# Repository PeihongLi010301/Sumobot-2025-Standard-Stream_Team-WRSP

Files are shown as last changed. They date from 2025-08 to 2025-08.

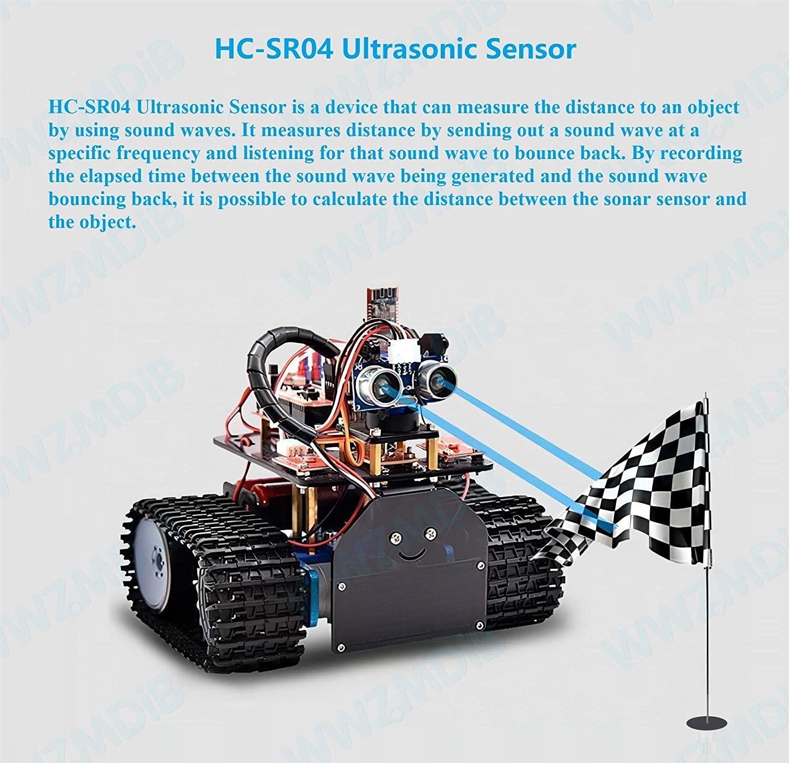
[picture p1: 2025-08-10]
Sumobot组件技术文档/HC-SR04 Specs4.jpg

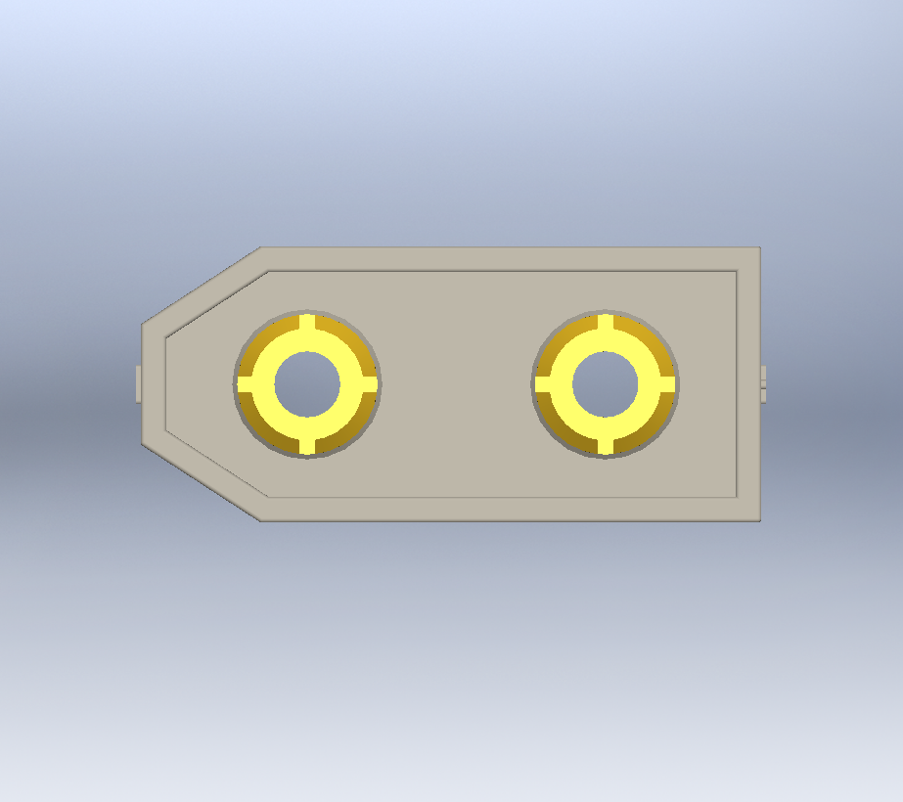
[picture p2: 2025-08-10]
MechanicalDesign_HM/Kit Components/LiPO/xt60-male-connector-3.snapshot.5/male connector top.png

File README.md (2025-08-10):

# Sumobot 2025 Standard Stream 相扑机器人标准组比赛
- 比赛组织方：UNSW Robotics and Mechatronics Society (RAMSoc)
- 团队名：WRSP（后改名为LRSP但未正式提交赛组委修改）
- 团队成员：李培泓（Peihong Li），余政阳（Zhengyang Yu），Suria，Sharath
- 比赛时间：2025年7月31日
- 核心硬件：Arduino Nano + L298N电机驱动模块 + HC-SR04超声波传感器模块×3 + KY-033红外传感器模块×2 + 直流减速电机×2

## 比赛概述
Sumobot 比赛遵循传统相扑比赛的核心规则，有两台自主机器人在擂台上对抗，目标是将对手推出擂台外
### 赛制规则
- 比赛流程：
  - 每场比赛最多 3 局，每局最长 2 分钟
  - 裁判发出开始信号后需等待 5 秒才可行动
  - 当对手被推出擂台外（身体任何部分触地）即判胜
  - 若时间到未分出胜负，裁判将根据技术表现等决定胜负
- 限制：
  - 最大尺寸：200mm × 200mm
  - 最大重量：1kg
  - 预算不超过 A$200
  - 只能使用组委会提供的套件和预先批准的额外零件
  - 不可改动传动系统，不可使用磁铁或粘性物质增加抓地力
### 擂台规格
- 外径：120cm
- 内径（黑色比赛区）：115cm
- 白边宽度：2.5cm
- 材质：18mm厚MDF板，表面喷漆

## 我们的机器人设计
### 机械结构设计与优化
- 低重心、宽底盘设计：SolidWorks建模，提升稳定性与抗翻能力 
- 重量分布优化：将电池、电机等大重量组件靠近底盘放置，便于快速转向和推挤时重心稳定  
- 月牙形边缘 + 斜坡楔组合前铲设计：解决单一楔形设计无法限制对手逃离的问题  
- 壳体与盖板通过PLA材料3D打印得到
### 控制架构
- Arduino Nano 作为主控
- 有限状态机（FSM）：
  - `SEARCHING`：原地旋转寻找对手
  - `ATTACKING`：持续向前推进（50ms 步长），每步检测边缘和对手位置
  - `AVOIDING_EDGE`：立即停车 → 后退 → 定时 ±90° 转向
- 边缘检测优先：一旦触发立即中断其他动作
### 传感器
- HC-SR04超声波传感器：前 / 左 / 右 三路，用于对手定位
- 红外循迹传感器：用于检测场地白边，防止跌落
- 去抖动机制：边缘检测需连续命中 `EDGE_DETECT_CONFIRM_COUNT=2` 次才确认有效
### 运动控制
- 时间式 PID 转向（输出为转向时长 ms）：
  - 固定全功率转动，避免低速死区
  - 参数：`kp=4.0, ki=0.8, kd=1.5`
  - 一阶低通滤波 + 抗积分饱和（±50）+ 最大输出限制（500ms）
- 90°定时转向：默认400ms（可调整）
- `DEGREES_TO_MS = 4.4`：实测转角-时间标定常数，即满功率旋转 1° ≈ 4.4 ms，可用于精确角度控制
### 电源与安全
- L298N双路驱动
- 按规则要求，电池串联 1A–5A 保险丝
- 所有长动作均设定时间上限，防止卡死
### 代码亮点
- 编程语言：Arduino C++
- 核心特性：
  - 模块化函数封装运动与传感器逻辑
  - 状态机逻辑保证行为可预测
  - 传感器融合进行对手定位
  - 50ms 步长攻击循环，快速响应场上变化
  - 时间式 PID 转向，减少抖动并提升一致性

### 核心参数一览
EDGE_DETECT_CONFIRM_COUNT = 2   // 连续两次命中才判定边缘
ATTACK_STEP = 50                // 攻击步长 ms
MAX_ATTACK_TIME = 1200          // 单次攻击最长时间 ms
kp = 4.0, ki = 0.8, kd = 1.5    // PID 参数
MAX_CONTROLLER_OUTPUT = 500     // 最大转向时长 ms
DEGREES_TO_MS = 4.4             // 每度旋转耗时 ms

### 文件说明
- 比赛规则详见：参赛规则说明书（英文版）_OFFICIAL SUMOBOTS RULE BOOK 2025.pdf
- 完整源码：详见Sumobot2025_Code.ino。代码内包含注释，说明设计思路与可调参数
- 完整模型：详见文件夹 MechanicalDesign_HM
    - 此文件包含初代、二代、三代的设计方案，如需查看最终方案的完整装配文件，请查看 MechanicalDesign_HM\Integrated Design_HM\Sumobot2025_ID_2nd.SLDASM
    - 如需查看最终方案的壳体设计文件，请查看 MechanicalDesign_HM\最终壳体设计方案\Chasis_ID_3rd.STEP
- 所用元件的规格及参数详细说明：详见文件夹 Sumobot组件技术文档 
- 比赛视频：请通过 比赛视频链接.txt 的百度网盘链接查看
- 实物及制作过程、参赛过程图片：请见文件夹 实物及过程图片

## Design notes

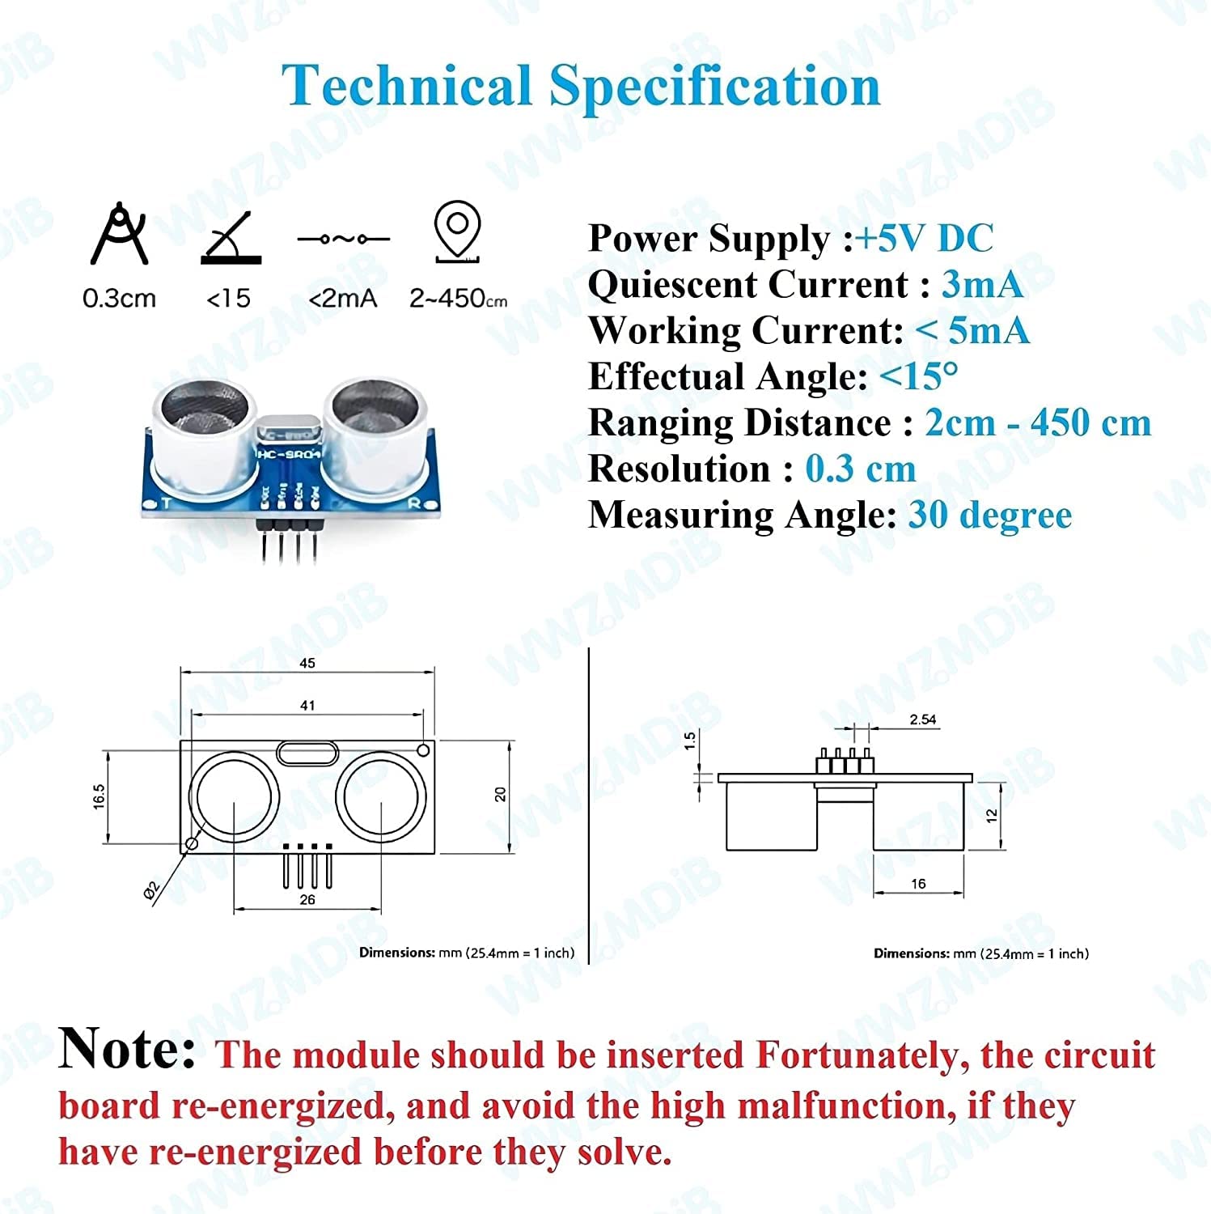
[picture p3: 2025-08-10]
Sumobot组件技术文档/HC-SR04 Specs1.jpg

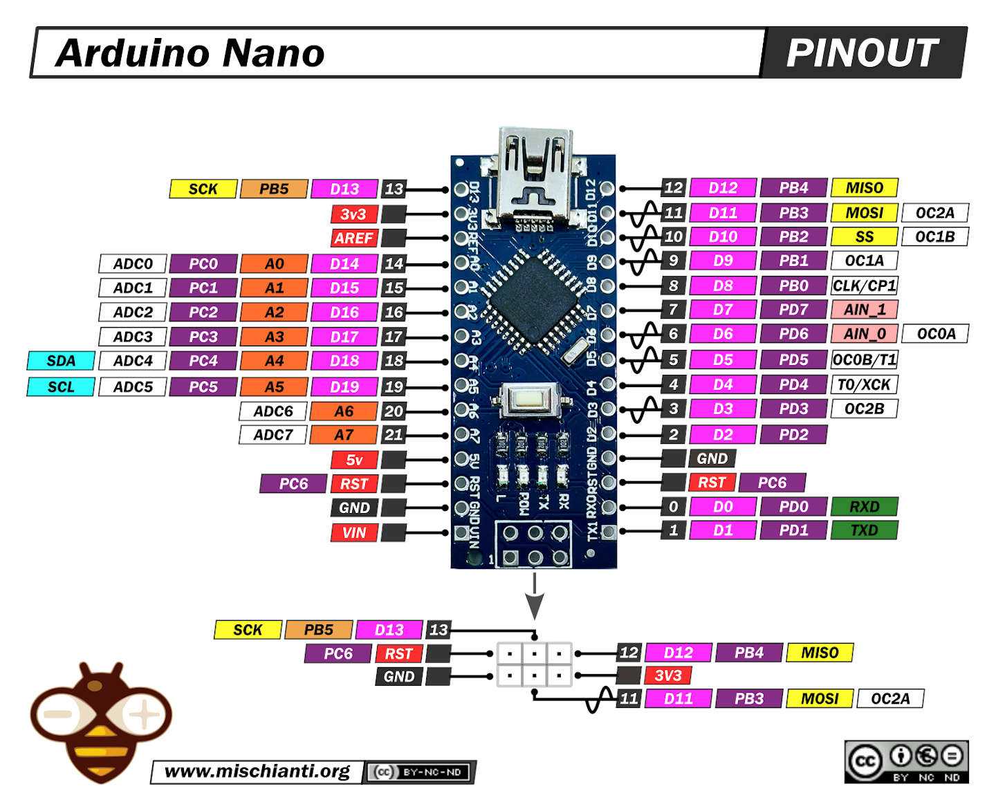
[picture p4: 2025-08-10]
Sumobot组件技术文档/Nano Pinout.jpg

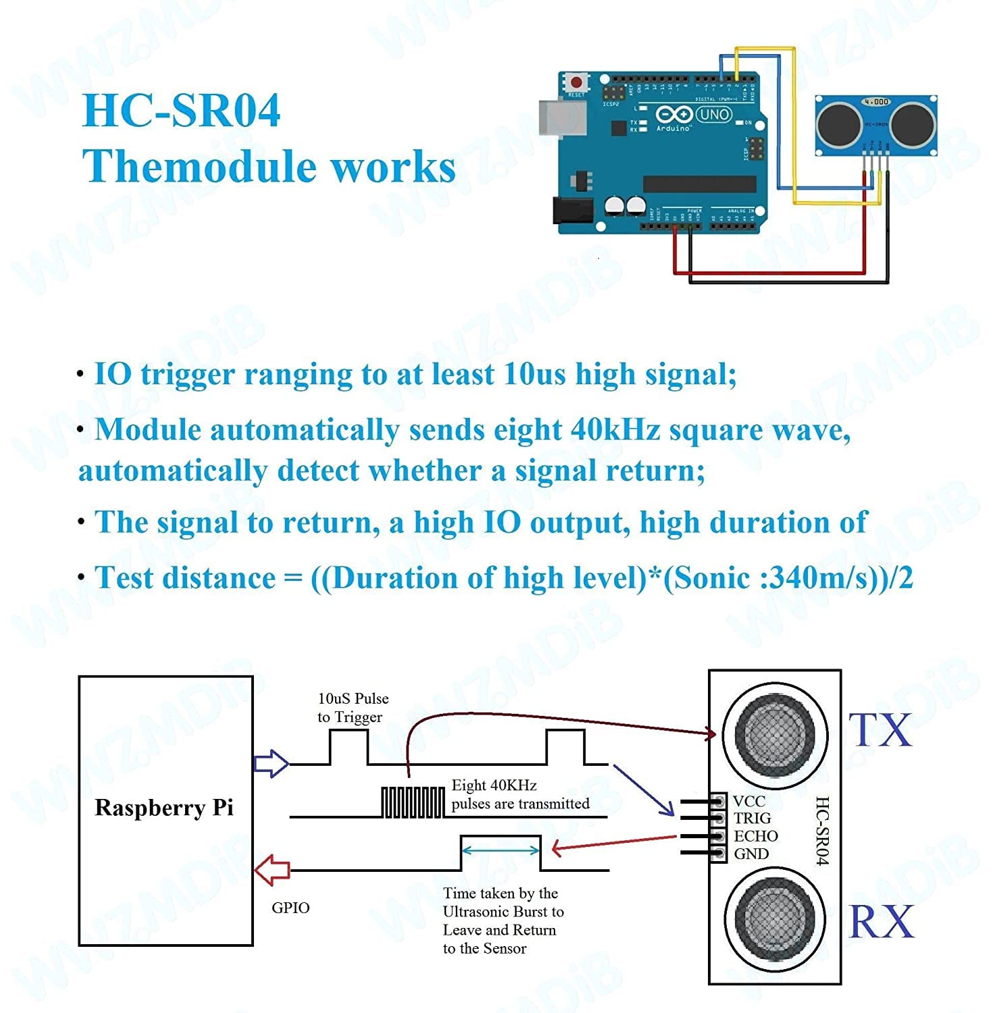
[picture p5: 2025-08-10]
Sumobot组件技术文档/HC-SR04 Specs3.jpg

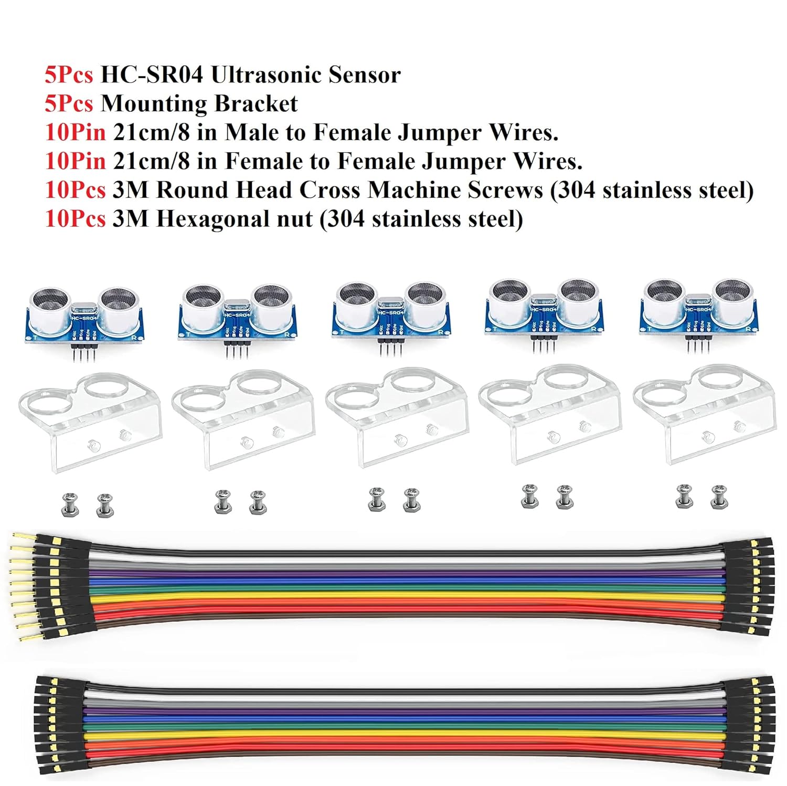
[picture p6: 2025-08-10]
Sumobot组件技术文档/HC-SR04 Specs2.jpg

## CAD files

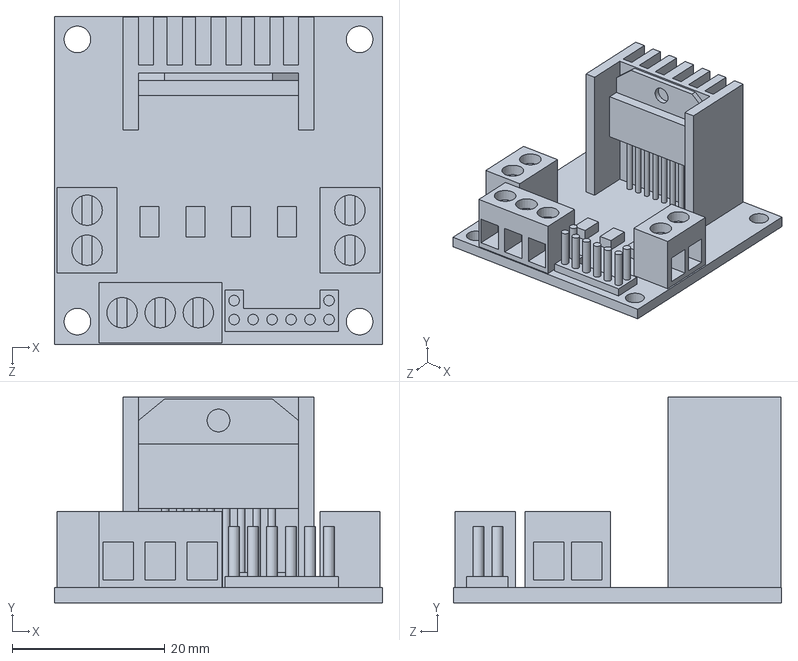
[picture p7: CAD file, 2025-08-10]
MechanicalDesign_HM/CAD Imports/L298N_Stepper_motor_driver.SLDPRT
43.0 x 27.0 x 43.0 mm

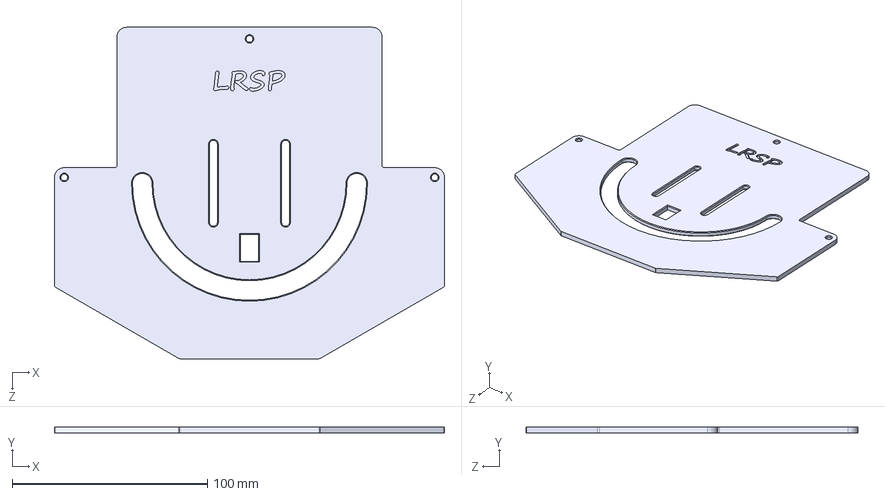
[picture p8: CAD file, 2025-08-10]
MechanicalDesign_HM/Integrated Design_HM/Lid.STEP
200.0 x 3.00 x 170.0 mm

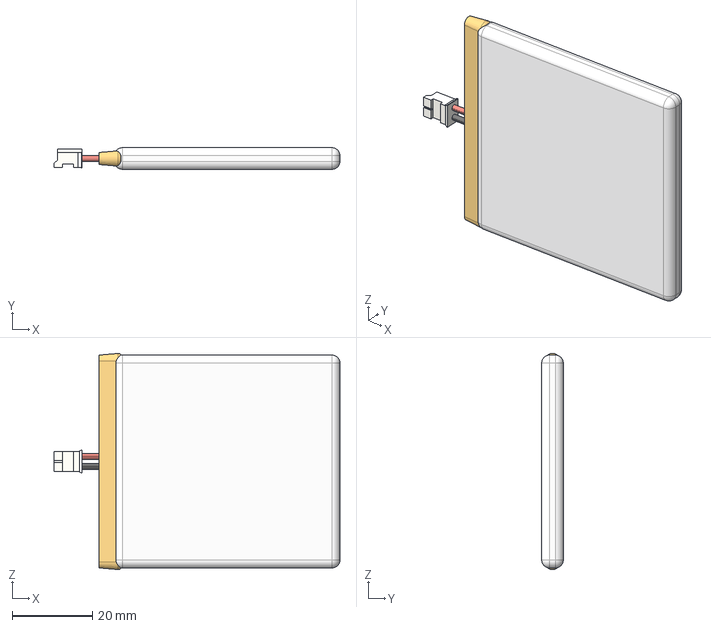
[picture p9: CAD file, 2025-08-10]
MechanicalDesign_HM/Kit Components/LiPO/3-7v-lipo-battery/LiPo Battery v5.step
71.2 x 5.38 x 53.8 mm

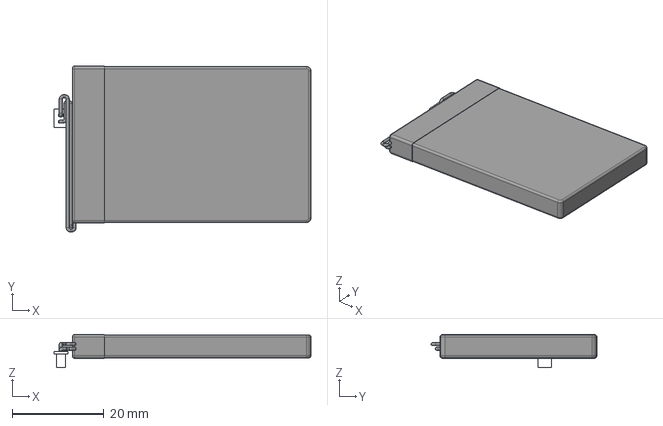
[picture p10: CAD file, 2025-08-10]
MechanicalDesign_HM/Kit Components/LiPO/Bateria_litio_523450/Litio_523450.step
56.0 x 36.2 x 7.20 mm
Conector

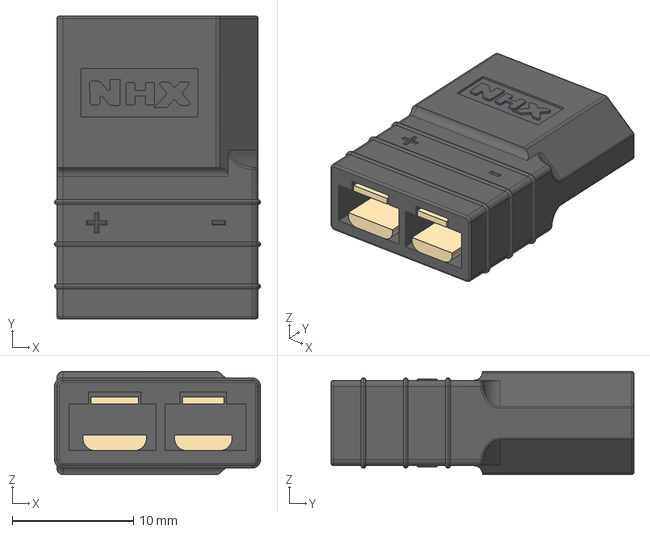
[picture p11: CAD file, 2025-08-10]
MechanicalDesign_HM/Kit Components/LiPO/traxxas-id-to-xt-60-connector-1.snapshot.1/Traxxas iD to XT-60 connector.step
17.0 x 25.0 x 8.50 mm

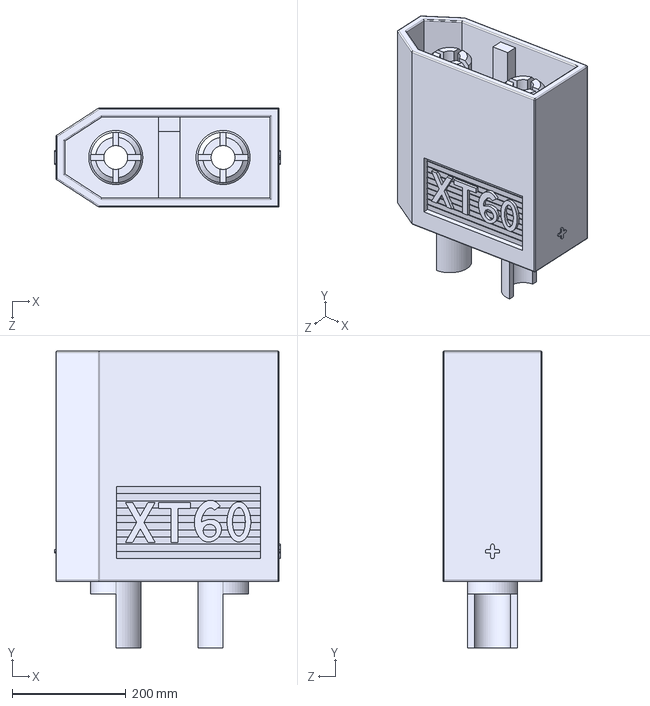
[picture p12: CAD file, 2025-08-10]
MechanicalDesign_HM/Kit Components/LiPO/xt60-male-connector-3.snapshot.5/male connector.STEP
398.8 x 523.2 x 175.3 mm

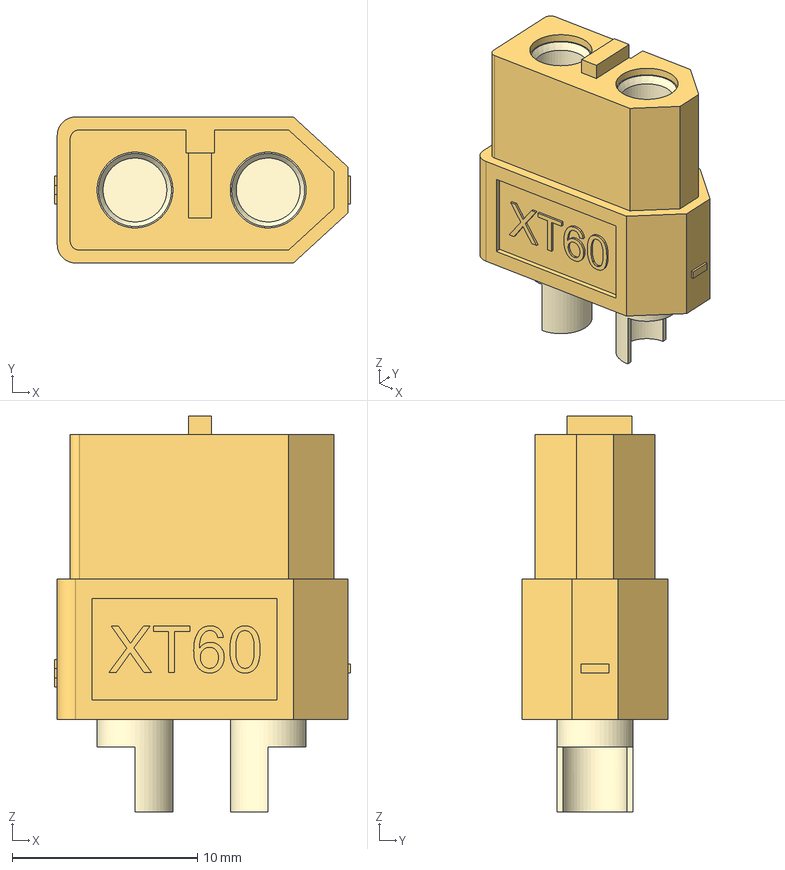
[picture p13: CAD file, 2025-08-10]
MechanicalDesign_HM/Kit Components/LiPO/xt60-plug-1.snapshot.1/XT60 Plug v4.step
16.0 x 7.90 x 21.4 mm

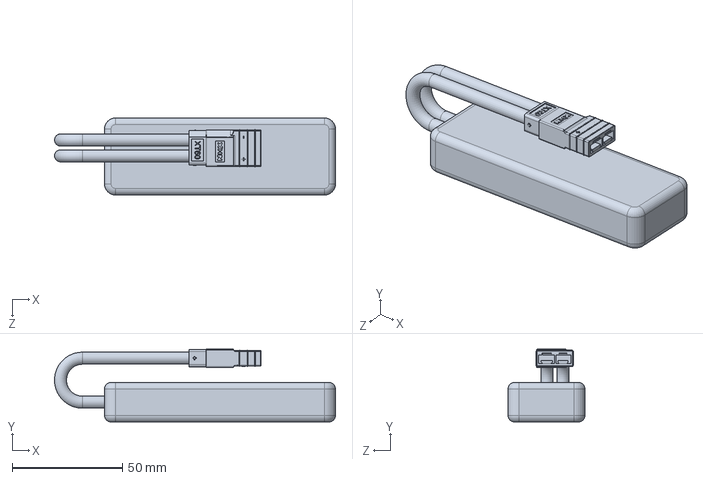
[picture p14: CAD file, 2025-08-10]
MechanicalDesign_HM/Kit Components/Simplified Components_asm2prt/LiPO Battery.SLDPRT
127.7 x 33.2 x 35.0 mm

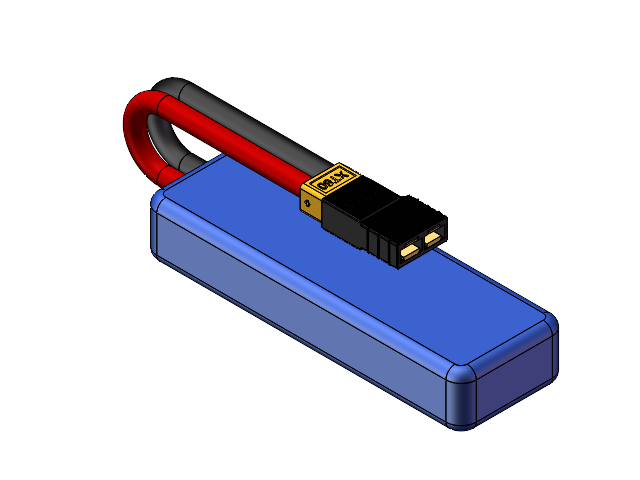
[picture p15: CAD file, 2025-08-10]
MechanicalDesign_HM/Kit Components/LiPO/LiPO Battery.SLDASM
LiPO Battery_sinConnector_old
Pins.step
XT60 Plug_1-0.step
Traxxas iD to XT-60 connector_3.step

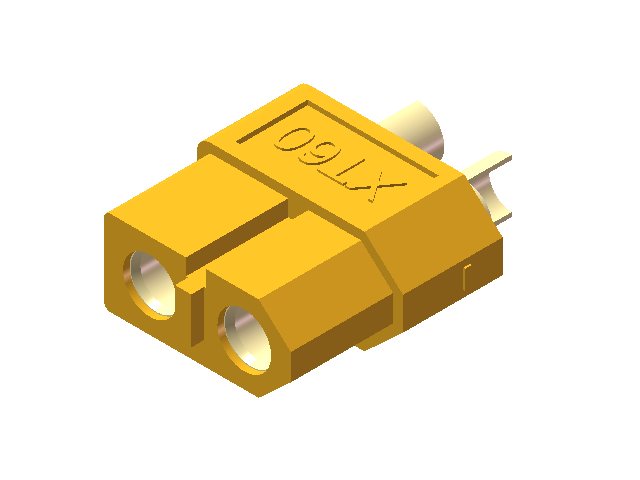
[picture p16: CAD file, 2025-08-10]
MechanicalDesign_HM/Kit Components/LiPO/XT60 Plug v4.SLDASM
Pins.step
XT60 Plug_1-0.step

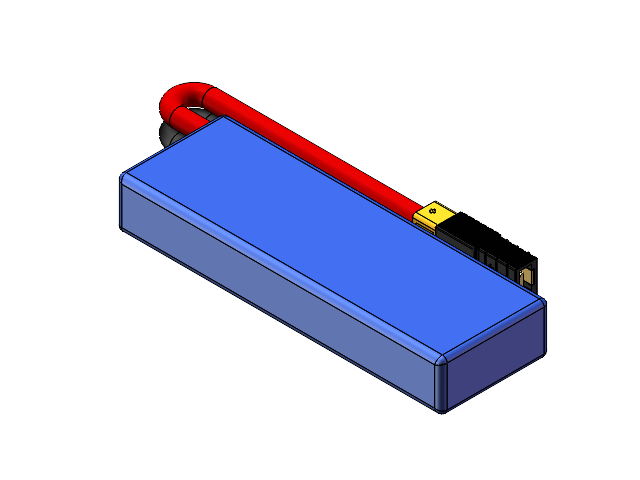
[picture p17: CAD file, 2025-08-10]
MechanicalDesign_HM/Kit Components/LiPO/LiPO Battery_new.SLDASM
LiPO Battery_sinConnector_new
Pins.step
XT60 Plug_1-0.step
Traxxas iD to XT-60 connector_3.step

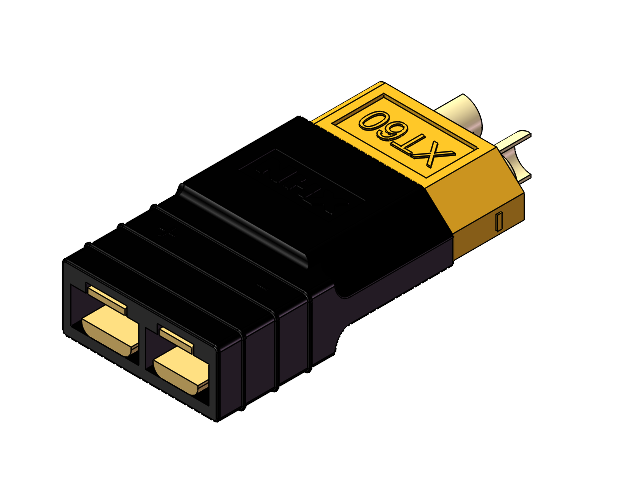
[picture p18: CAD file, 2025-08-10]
MechanicalDesign_HM/Kit Components/LiPO/XT60.SLDASM
Pins.step
XT60 Plug_1-0.step
Traxxas iD to XT-60 connector_3.step

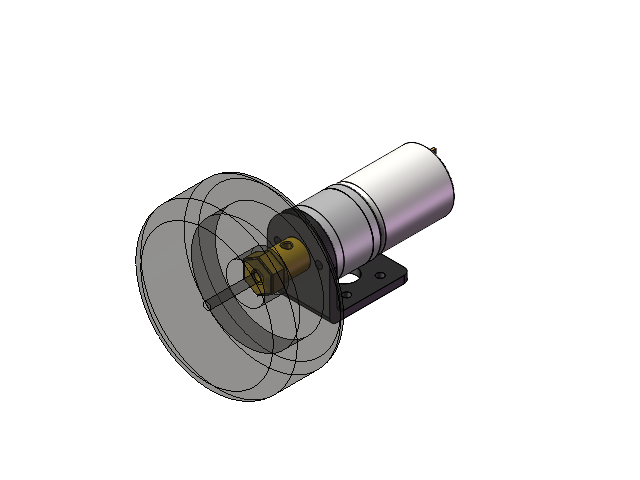
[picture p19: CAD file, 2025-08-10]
MechanicalDesign_HM/Kit Components/Motor_Bracket_Wheel.SLDASM
L-type Motor Mount Bracket
Motor
Brass Motor Shaft Coupler
Wheel_transparent

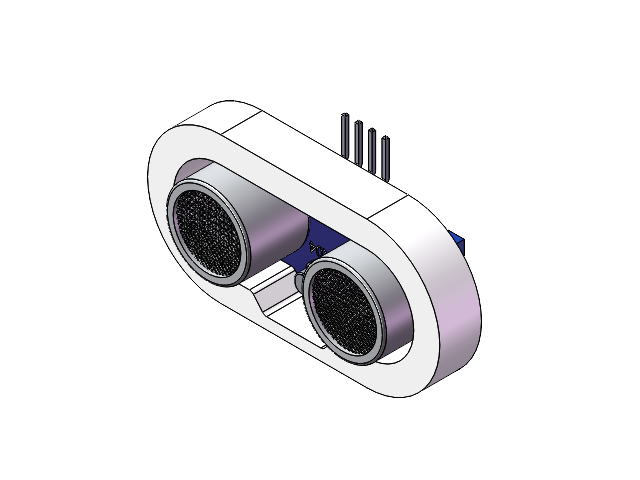
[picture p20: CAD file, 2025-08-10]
MechanicalDesign_HM/Kit Components/Ultrasonic Sensor with Holder.SLDASM
Ultrasonic Holder
Ultrasonic Sensor

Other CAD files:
MechanicalDesign_HM/Kit Components/LiPO/Traxxas iD to XT-60 connector.SLDASM
MechanicalDesign_HM/Integrated Design_HM/Ver_3rd/Lid.STEP
MechanicalDesign_HM/Modular Design_HM/Wedge.gcode.3mf
MechanicalDesign_HM/Brass Motor Shaft Coupler.SLDPRT
MechanicalDesign_HM/CAD Imports/25ga-370-280-rpm-dc Motor.stp
MechanicalDesign_HM/Chasis.SLDPRT
MechanicalDesign_HM/Chasis_HM.SLDPRT
MechanicalDesign_HM/Chasis_HMTest.SLDPRT
MechanicalDesign_HM/Component Layer.SLDPRT
MechanicalDesign_HM/Component Layer.STEP
MechanicalDesign_HM/Integrated Design_HM/Chasis_ID.3mf
MechanicalDesign_HM/Integrated Design_HM/Chasis_ID.SLDPRT
MechanicalDesign_HM/Integrated Design_HM/Chasis_ID.STEP
MechanicalDesign_HM/Integrated Design_HM/Chasis_ID.gcode.3mf
MechanicalDesign_HM/Integrated Design_HM/Chasis_ID_3rd.SLDPRT
MechanicalDesign_HM/Integrated Design_HM/Lid.SLDPRT
MechanicalDesign_HM/Integrated Design_HM/Lid_old.SLDPRT
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

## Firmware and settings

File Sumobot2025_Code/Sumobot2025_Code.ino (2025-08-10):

/* Sumobot 2025 – Standard Stream
 * 代码作者: Peihong Li (李培泓), Zhengyang Yu (余政阳)
 *
 * 简介:
 *  - 三向超声 (前/左/右) + 双IR边缘检测 的对抗机器人
 *  - 以状态机 (SEARCHING / ATTACKING / AVOIDING_EDGE) 管理策略，边缘回避优先级最高
 *  - 进攻采用“50ms步长”的持续逼抢，每步都复核边缘/目标，安全且响应快
 *  - 关键改进：将PID输出由“PWM幅值”改为“固定功率下的转向时长(ms)” 结合一阶滤波、积分限幅与最大输出限制，显著提升低速段纠偏稳定性
 *
 * Overview:
 *  - Sumo robot using 3 HC-SR04 sonars (front/left/right) + dual IR line sensors.
 *  - Finite-state machine: SEARCHING / ATTACKING / AVOIDING_EDGE (edge-avoid has highest priority).
 *  - Continuous attack in 50ms steps to re-check edge/opponent frequently (safe & responsive).
 *  - Key improvement: time-based PID turning (ms) with filtering, anti-windup and output cap,
 *    much more stable than PWM-difference at low speed.
 *
 * 硬件连接 Pin Mapping:
 *  - L298N: ENA=D10(右), ENB=D11(左), R_FWD=D9, R_BWD=D8, L_BWD=D7, L_FWD=D6
 *  - 超声波: Front TRIG=D3/ECHO=D2, Left TRIG=D5/ECHO=D4, Right TRIG=A0/ECHO=A1
 *  - IR边缘: 左 A2 (白边时高), 右 A3 (白边时低)
 *
 * 关键参数 Key Params:
 *  - EDGE_DETECT_CONFIRM_COUNT=2：IR需连续命中2次才判边缘，抑制抖动
 *  - ATTACK_STEP=50ms, MAX_ATTACK_TIME=1200ms：逼抢步长 最长时长
 *  - PID: kp=4.0, ki=0.8, kd=1.5；积分限幅±50；MAX_CONTROLLER_OUTPUT=500ms
 *  - DEGREES_TO_MS=4.4：测得的机器人以满功率（PWM=255）转动 1° 所需的时间 ≈ 4.4 毫秒
 *  - 90°定时转向 delay(400)：实测所得
 *
 * 调参建议 Tuning Tips:
 *  - IR阈值：EDGE_THRESHOLD_LEFT/RIGHT 依据赛道白边反射特性微调
 *  - 攻击节奏：ATTACK_STEP 越小越灵敏但CPU 循环频率太高，频繁 delay + 传感器读取，会浪费时间在I/O上，可能还没前进出明显位移就被检测打断，逼抢动作变得断断续续，故选用50ms
 *  - PID：先调 kp 至能稳定纠偏，再加 kd 抑制抖动，最后加小幅 ki 修正系统性偏差
 *  - 最大输出：MAX_CONTROLLER_OUTPUT 控制单次转向上限，防呆/防暴走
 *
 * 安全策略 / Safety:
 *  - detect_edge() 结果一旦成立，立即抢占，执行 avoid_edge()（停→退→90°转）
 *  - 所有长动作均设置上限（如攻击总时长），防止卡死
 *
 * 已知限制 / Known Limits:
 *  - 超声测距存在盲区（<2cm无法探测）与偶发timeout，已通过滤波/上限处理提高鲁棒性
 *  - 90°转向基于定时，非闭环角度；如需精确角度，需改用带编码器的电机（本赛禁用）
 */

// -------------------- Motor control --------------------
#define ENA 10 // right PWM (L298N ENB/ENA命名随接线)
#define ENB 11 // left  PWM
#define MOTOR_RIGHT_FORWARD 9
#define MOTOR_RIGHT_BACKWARD 8
#define MOTOR_LEFT_BACKWARD 7
#define MOTOR_LEFT_FORWARD 6

// -------------------- IR sensors (edge detection) --------------------
#define IR_SENSOR_LEFT A2   // 左IR：白边时读数高（~920），阈值设高些
#define IR_SENSOR_RIGHT A3  // 右IR：白边时读数低（~30），阈值设低些

// -------------------- Ultrasonic (HC-SR04) --------------------
#define TRIG_PIN_LEFT 5
#define ECHO_PIN_LEFT 4
#define TRIG_PIN_FRONT 3 
#define ECHO_PIN_FRONT 2
#define TRIG_PIN_RIGHT A0
#define ECHO_PIN_RIGHT A1

// Speed of sound cm/us (未直接使用，保留为可能的精确定义)
#define SPEED_OF_SOUND 0.034

// Sonar clamp range
#define MAX_DISTANCE 90   // 超出视为无敌人
#define MIN_DISTANCE 2    // 超声波传感器自身的探测下限

// ---------- Edge Detection Constants ----------
#define EDGE_THRESHOLD_LEFT 700   // 左IR高于此认为白边
#define EDGE_THRESHOLD_RIGHT 50   // 右IR低于此认为白边
#define WHITE_SURFACE 1
#define BLACK_SURFACE 0

// ---------- Edge detection debounce ----------
bool left_edge_detected = false;
bool right_edge_detected = false;
int edge_detect_count = 0;                  // 连续确认计数
const int EDGE_DETECT_CONFIRM_COUNT = 2;    // 去抖：至少命中2次才判定

// ---------- PID (time-based output in ms) ----------
float kp = 4.0;
float ki = 0.8;
float kd = 1.5;

float prev_error = 0;
float error = 0;
float integral = 0;                 // 抗积分饱和在控制函数中
float controller_output = 0;        // 输出：转向时间 (ms)
float MAX_CONTROLLER_OUTPUT = 500;  // 单次最大转向时长 (ms)

int flag = 0;                       // 1:right, 2:left（用于选择误差来源）
float filtered_error = 0;           // 一阶滤波误差
float filtered_dir_error = 0;

// Rotation constant (if need angle-based timing)
#define DEGREES_TO_MS 4.4

// ---------- FSM ----------
enum RobotState { SEARCHING, ATTACKING, AVOIDING_EDGE };
RobotState currentState = SEARCHING;

void setup() {
  Serial.begin(9600);

  // Motors
  pinMode(ENA, OUTPUT);
  pinMode(ENB, OUTPUT);
  pinMode(MOTOR_LEFT_FORWARD, OUTPUT);
  pinMode(MOTOR_LEFT_BACKWARD, OUTPUT);
  pinMode(MOTOR_RIGHT_FORWARD, OUTPUT);
  pinMode(MOTOR_RIGHT_BACKWARD, OUTPUT);

  // IR
  pinMode(IR_SENSOR_LEFT, INPUT);
  pinMode(IR_SENSOR_RIGHT, INPUT);

  // Sonars
  pinMode(TRIG_PIN_FRONT, OUTPUT);
  pinMode(ECHO_PIN_FRONT, INPUT);
  pinMode(TRIG_PIN_LEFT, OUTPUT);
  pinMode(ECHO_PIN_LEFT, INPUT);
  pinMode(TRIG_PIN_RIGHT, OUTPUT);
  pinMode(ECHO_PIN_RIGHT, INPUT);

  delay(5000); // 开赛前预留校准/放置时间
  Serial.println("Sumobot initialized!");
}

void loop() {
  // 1) 边缘优先：一旦探测到边缘，立刻进入回避流程
  if (detect_edge()) {
    currentState = AVOIDING_EDGE;
    avoid_edge();
    integral = 0;     // 切状态时重置积分，防止残留
    return;
  }

  // 2) 正常对抗逻辑
  currentState = SEARCHING;
  String direction = detect_robot_dir();  // 基于三向最小距离选择方向

  if (direction == "front") {
    currentState = ATTACKING;
    attack_continuously();  // 50ms 步长的持续逼抢（内含边缘/目标复核）
    integral = 0;           // 直行后复位积分
  } else if (direction == "right") {
    flag = 1;
    turn_right_time(get_dir_error(flag));  // 时间式PID：输出为delay(ms)
  } else if (direction == "left"){
    flag = 2;
    turn_left_time(get_dir_error(flag));
  } else {
    rotate();  // 未锁定目标：原地对转进行检索
  }
}

// 持续逼抢：每50ms复核一次边缘与目标，以安全与响应速度为平衡
void attack_continuously() {
  int attack_duration = 0;
  const int MAX_ATTACK_TIME = 1200; // 单次逼抢上限
  const int ATTACK_STEP = 50;       // 50ms步长

  while (attack_duration < MAX_ATTACK_TIME) {
    if (detect_edge()) {
      stop_motors();
      move_backward();
      delay(10);
      return;
    }

    String current_direction = detect_robot_dir();
    if (current_direction != "front") {
      stop_motors(); // 目标偏移，立即停止本次逼抢
      return;
    }

    move_forward();
    delay(ATTACK_STEP);
    attack_duration += ATTACK_STEP;
  }
  return;
}

// 原地对转（右轮前进，左轮后退）
void rotate() {
  digitalWrite(MOTOR_RIGHT_FORWARD, HIGH);
  digitalWrite(MOTOR_RIGHT_BACKWARD, LOW);
  analogWrite(ENB, 255);

  digitalWrite(MOTOR_LEFT_FORWARD, LOW);
  digitalWrite(MOTOR_LEFT_BACKWARD, HIGH);
  analogWrite(ENA, 255);
}

// ---- 边缘检测（带去抖）----
bool detect_edge() {
  int left_sensor = analogRead(IR_SENSOR_LEFT);
  int right_sensor = analogRead(IR_SENSOR_RIGHT);

  // 判定：左高于阈值/右低于阈值即视为白边
  left_edge_detected = (left_sensor > EDGE_THRESHOLD_LEFT);
  right_edge_detected = (right_sensor < EDGE_THRESHOLD_RIGHT);

  if (left_edge_detected || right_edge_detected) {
    edge_detect_count++;     // 连续命中次数+1
  } else {
    edge_detect_count = 0;   // 只要一次不命中就清零
  }
  return edge_detect_count >= EDGE_DETECT_CONFIRM_COUNT;
}

// ---- 回避流程：停→退→按侧转90°（定时），最后清状态 ----
void avoid_edge() {
  stop_motors();
  delay(10);

  move_backward();
  delay(300);

  stop_motors();
  delay(10);

  if (left_edge_detected && !right_edge_detected) {
    turn_right_90();
  } else if (right_edge_detected && !left_edge_detected) {
    turn_left_90();
  } else if (left_edge_detected && right_edge_detected) {
    // 双侧同时触边：加大后退并右转（可改为随机）
    move_backward();
    delay(300);
    turn_right_90();
  }

  // 清空缓存，避免连锁触发
  left_edge_detected = false;
  right_edge_detected = false;
  edge_detect_count = 0;

  stop_motors();
  delay(10);
}

// ---- 基于三向距离的对手方位判定（取最小者）----
String detect_robot_dir() {
  float front_dist = front_distance();
  float left_dist = left_distance();
  float right_dist = right_distance();

  if ((front_dist < left_dist) && (front_dist < right_dist)) {
    return "front";
  } else if ((left_dist < front_dist) && (left_dist < right_dist)) {
    return "left";
  } else if ((right_dist < front_dist) && (right_dist < left_dist)) {
    return "right";
  } else {
    return "None";
  }
}

// -------------------- Motion primitives --------------------
void move_forward() {
  analogWrite(ENA, 255);
  analogWrite(ENB, 255);
  digitalWrite(MOTOR_LEFT_FORWARD, HIGH);
  digitalWrite(MOTOR_LEFT_BACKWARD, LOW);
  digitalWrite(MOTOR_RIGHT_FORWARD, HIGH);
  digitalWrite(MOTOR_RIGHT_BACKWARD, LOW);
}

void move_backward() {
  analogWrite(ENA, 200);
  analogWrite(ENB, 200);
  digitalWrite(MOTOR_LEFT_FORWARD, LOW);
  digitalWrite(MOTOR_LEFT_BACKWARD, HIGH);
  digitalWrite(MOTOR_RIGHT_FORWARD, LOW);
  digitalWrite(MOTOR_RIGHT_BACKWARD, HIGH);
}

void stop_motors() {
  analogWrite(ENA, 0);
  analogWrite(ENB, 0);
  digitalWrite(MOTOR_LEFT_FORWARD, LOW);
  digitalWrite(MOTOR_LEFT_BACKWARD, LOW);
  digitalWrite(MOTOR_RIGHT_FORWARD, LOW);
  digitalWrite(MOTOR_RIGHT_BACKWARD, LOW);
}

// 90°定时转向：400ms为实测经验值
void turn_left_90() {
  analogWrite(ENA, 255);
  analogWrite(ENB, 255);
  digitalWrite(MOTOR_LEFT_FORWARD, LOW);
  digitalWrite(MOTOR_LEFT_BACKWARD, HIGH);
  digitalWrite(MOTOR_RIGHT_FORWARD, HIGH);
  digitalWrite(MOTOR_RIGHT_BACKWARD, LOW);
  delay(400);
  stop_motors();
}

void turn_right_90() {
  analogWrite(ENA, 255);
  analogWrite(ENB, 255);
  digitalWrite(MOTOR_LEFT_FORWARD, HIGH);
  digitalWrite(MOTOR_LEFT_BACKWARD, LOW);
  digitalWrite(MOTOR_RIGHT_FORWARD, LOW);
  digitalWrite(MOTOR_RIGHT_BACKWARD, HIGH);
  delay(400);
  stop_motors();
}

// ---- 方向误差：使用 |F-R| 或 |F-L|，并做轻滤波 ----
float get_dir_error(int flag) {
  float raw_error;
  if (flag == 1) {
    raw_error = abs(front_distance() - right_distance());
  } else if (flag == 2) {
    raw_error = abs(front_distance() - left_distance());
  } else {
    raw_error = 0;
  }
  // 轻滤波，抑制超声瞬时噪声
  filtered_dir_error = 0.8 * filtered_dir_error + 0.2 * raw_error;

  Serial.print("Error:");
  Serial.println(filtered_dir_error);
  return filtered_dir_error;
}

// ---- 时间式PID控制器：输出为“转向时长 (ms)” ----
float time_controller(float error) {
  // 一阶低通滤波，稳定误差
  filtered_error = 0.9 * filtered_error + 0.1 * error;

  // 小误差死区：避免无意义微动
  if (filtered_error < 1.5) {
    return 0;
  }

  integral += filtered_error;
  // 抗积分饱和：防止长时间偏差导致过大超调
  integral = constrain(integral, -50, 50);

  float derivative = filtered_error - prev_error;
  controller_output = kp * filtered_error + ki * integral + kd * derivative;

  // 限幅：确保单次转向时长 <= 500ms
  controller_output = constrain(controller_output, 0, MAX_CONTROLLER_OUTPUT);

  prev_error = filtered_error;

  Serial.println("controller_output (ms):");
  Serial.println(controller_output);
  return controller_output; // ms
}

// ---- 右转（时间式）：全功率 + 定时，避免低速死区 ----
void turn_right_time(float error) {
  float turn_time = time_controller(error);
  if (turn_time > 0) {
    // 左轮前进、右轮后退 -> 右转
    digitalWrite(MOTOR_LEFT_FORWARD, HIGH);
    digitalWrite(MOTOR_LEFT_BACKWARD, LOW);
    analogWrite(ENB, 255);

    digitalWrite(MOTOR_RIGHT_FORWARD, LOW);
    digitalWrite(MOTOR_RIGHT_BACKWARD, HIGH);
    analogWrite(ENA, 255);

    delay(turn_time);
    stop_motors();
    delay(1); // 机械稳定
  }
}

// ---- 左转（时间式）----
void turn_left_time(float error) {
  float turn_time = time_controller(error);
  if (turn_time > 0) {
    // 右轮前进、左轮后退 -> 左转
    digitalWrite(MOTOR_RIGHT_FORWARD, HIGH);
    digitalWrite(MOTOR_RIGHT_BACKWARD, LOW);
    analogWrite(ENA, 255);

    digitalWrite(MOTOR_LEFT_FORWARD, LOW);
    digitalWrite(MOTOR_LEFT_BACKWARD, HIGH);
    analogWrite(ENB, 255);

    delay(turn_time);
    stop_motors();
    delay(1);
  }
}

// ---- 距离读数（带超时与上下限裁剪）----
float front_distance() { return get_distance(TRIG_PIN_FRONT, ECHO_PIN_FRONT) - 2; } // -2 作微校正
float left_distance()  { return get_distance(TRIG_PIN_LEFT,  ECHO_PIN_LEFT); }
float right_distance() { return get_distance(TRIG_PIN_RIGHT, ECHO_PIN_RIGHT); }

float get_distance(int TRIG_PIN, int ECHO_PIN) {
  digitalWrite(TRIG_PIN, LOW);
  delayMicroseconds(2);
  digitalWrite(TRIG_PIN, HIGH);
  delayMicroseconds(10);
  digitalWrite(TRIG_PIN, LOW);

  // 超时：30ms内未返回视为失败 -> 返回MAX_DISTANCE
  float duration = pulseIn(ECHO_PIN, HIGH, 30000);
  if (duration == 0) return MAX_DISTANCE;

  float distance = duration / 58.0; // HC-SR04 常用换算
  if (distance > MAX_DISTANCE) return MAX_DISTANCE;
  if (distance < MIN_DISTANCE)  return MIN_DISTANCE;
  return distance;
}
